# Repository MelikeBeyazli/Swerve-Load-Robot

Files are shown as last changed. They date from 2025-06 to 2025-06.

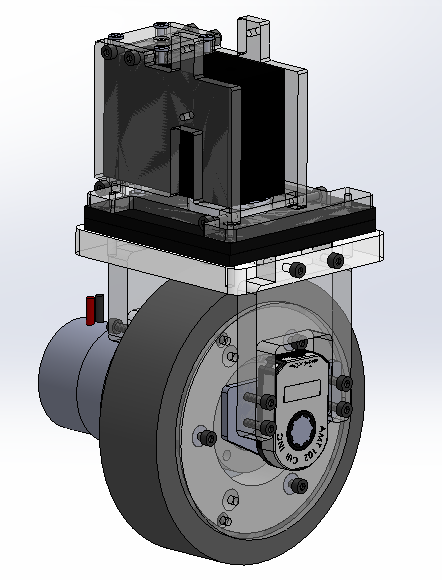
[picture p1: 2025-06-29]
Cad/2_Tekerler-Sümeyye/Yük Tekeri/swerve drive pic2.png

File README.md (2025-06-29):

# Swerve-Load-Robot — Tasarım & Mekanik Analiz Projesi  
*(Mekatronik Mühendisliği Tasarım Dersi, 2024 Bahar Dönemi)*

Bu depo; makaslı kaldırma mekanizması ve swerve‑drive tahrik sistemine sahip  
dört tekerlekli bir **yük robotunun** SolidWorks CAD dosyalarını ve ANSYS tabanlı  
mekanik analiz çıktılarının özetlerini içerir. Çalışma, 2024 ilkbaharında ders  
projesi olarak yürütülmüş ve aynı yıl bir ulusal sempozyum bildirisi ile hakemli  
dergi makalesi biçiminde yayınlanmıştır.

---

## 1 | Ekip ve Sorumluluklar

| Klasör | İçerik | Sorumlu Öğrenci |
|---|---|---|
| `cad/car_body/` | Beş karoser prototipi ve final gövde | **Melike Beyazlı** |
| `cad/chassis/`  | Sigma‑profil şasi tasarımları | **Görkem Burak Taşkın** |
| `cad/wheels/` | Yedi PU‑kaplı tahrik tekeri modeli | **Sümeyye Alp** |
| `cad/lift/` | Üç makaslı kaldırma tasarımı | **Zeynep Işık**, **Görkem B. Taşkın** |
| `cad/swerve-load-robot/` | Nihai bütünleşik montaj (.SLDASM) | Tüm ekip |
| `docs/` | • **Makale**: Mısır, O., Beyazlı, M., Alp, S., Taşkın, G. B., *vd.* (2024). *Design and Mechanical Analyses of Mobile Robot with Swerve Driving System*. **Türk Doğa ve Fen Dergisi, 13(4), 66‑84.** doi:10.46810/tdfd.1506516  <br>• **Bildiri**: Beyazlı, M., Alp, S., Taşkın, G. B., Işık, Z. (2024). *Dört Tekerlekli Yük Taşıma Özelliğine Sahip Otonom Mobil Robotun Geliştirilmesi.* UEBAS’24, 16‑17 Mart 2024.  |

---

## 2 | Çalışma Takvimi (2024)

| Ay | Önemli Adımlar |
|----|---|
| Şubat | Konsept belirleme; ilk karoser ve şasi çizimleri |
| Mart  | Teker prototipleri; IV. Ege Bilimsel Araştırmalar Sempozyumu bildirisi |
| Nisan | ANSYS Workbench kurulumu; malzeme kütüphanesi oluşturma |
| Mayıs | Karoser, şasi, teker ve kaldıraca ait ayrık FEA çalışmaları |
| Haziran | Nihai montaj **Swerve‑Load‑Robot** tamamlandı |
| Temmuz | Bandırma DergiPark makalesi tamaml anıp gönderildi |

---

## 3 | Klasör Yapısı

```
swerve-load-robot/
├── cad/
│   ├── car_body/            # Karoser taslakları
│   ├── chassis/             # Şasi modelleri
│   ├── wheels/              # Teker varyasyonları
│   ├── lift/                # Kaldırma mekanizmaları
│   └── swerve-load-robot/   # Nihai montaj (.SLDASM)
├── docs/
│   ├── Swerve...Robot_Tasarımı.docx
│   ├── Dört_Tekerlekli_Yük_Taşıma_Robot.pptx
│   └── Sunum_Özeti_Dört_Tekerlekli_Yük_Taşıma.docx
└── README.md
```

---

Bu özet, depodaki her bileşenin **kim** tarafından hazırlandığını ve **nerede**  
bulunduğunu netleştirir. Ayrıntılı CAD modelleri ve analiz raporları ilgili  
klasörlerde mevcuttur.

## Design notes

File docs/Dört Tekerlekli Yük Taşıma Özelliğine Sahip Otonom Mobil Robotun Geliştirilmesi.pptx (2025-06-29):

## Dört Tekerlekli Yük Taşıma Özelliğine Sahip Otonom Mobil Robotun Geliştirilmesİ

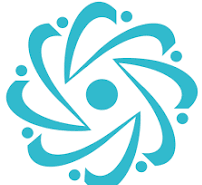
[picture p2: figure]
Bursa Teknik Üniversitesi | Bursa

Bursa Teknik Üniversitesi
Mekatronik Mühendisliği

Melike Beyazlı
Sümeyye Alp
Görkem Burak Taşkın
Zeynep Işık
Dr. Öğr. Üyesi Oğuz Mısır

## içindekiler

Endüstriyel Robotlara Giriş
Tasarlanan Aracın Görevleri
Elektronik ve Yazılım Tasarımı
Mekanik Tasarımı

## Endüstriyel Robotlara Giriş

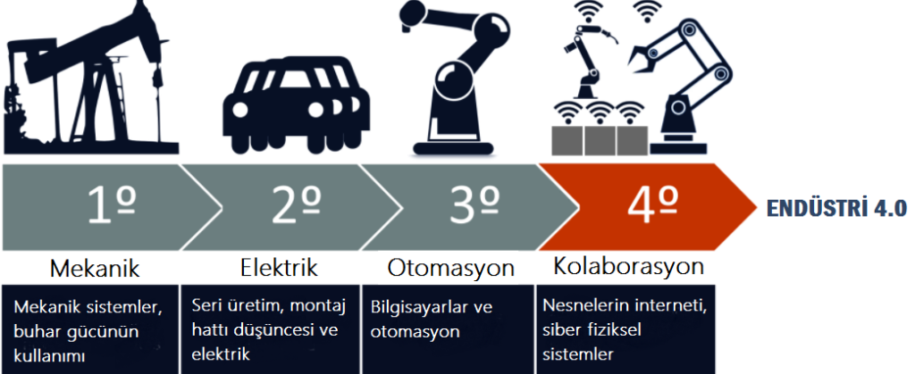
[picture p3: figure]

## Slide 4

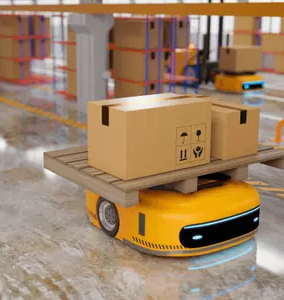
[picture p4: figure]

Endüstriyel kullanımda yaygın olarak kullanılan AGV'ler (Otonom Güdümlü Araçlar), otomatik olarak malzemeleri taşımak, yükleri yerinden almak ve belirlenmiş hedeflere teslim etmek için kullanılan otonom araçlardır. AGV'ler fabrikalarda, depolarda, lojistik merkezlerinde ve benzeri endüstriyel tesislerde yaygın olarak kullanılır.

## Tasarlanan Aracın Görevleri

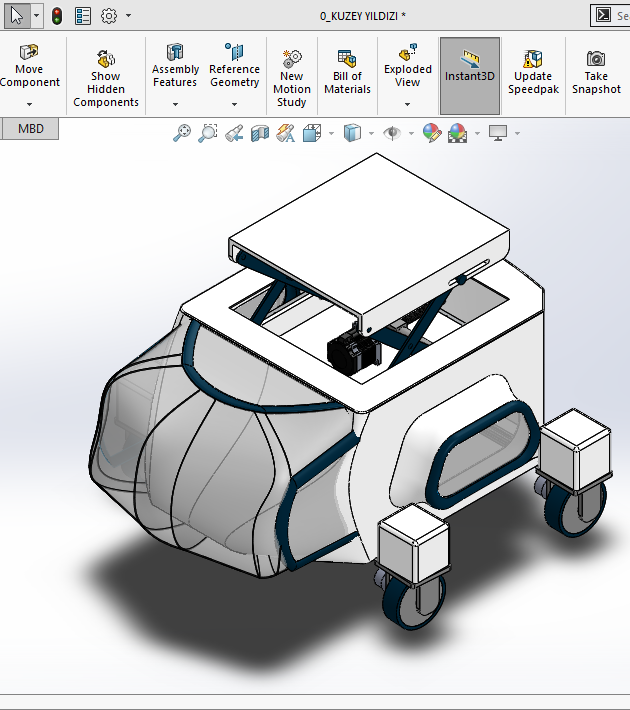
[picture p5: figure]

- Haritalandırma,
- Yol takibi,
- Engelden kaçınma,
- Yük alma bırakma,
- Fazla yük tespiti.

## Elektronik ve Yazılım Tasarımı

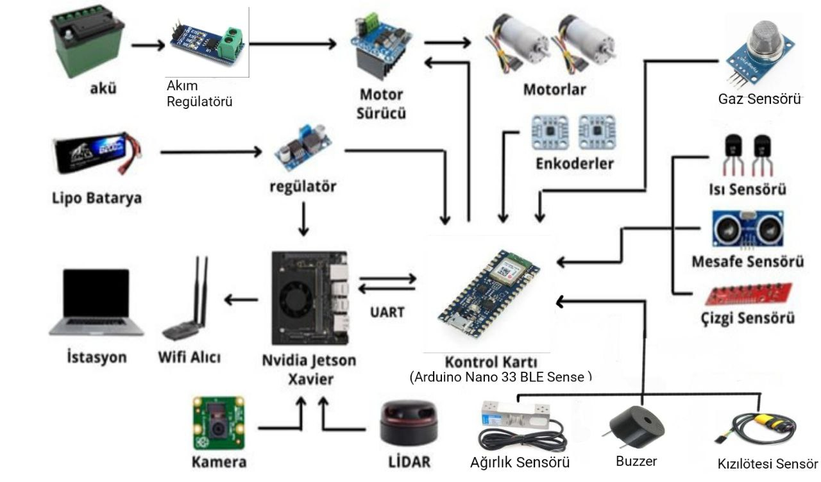
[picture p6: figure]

## Mekanik Tasarım

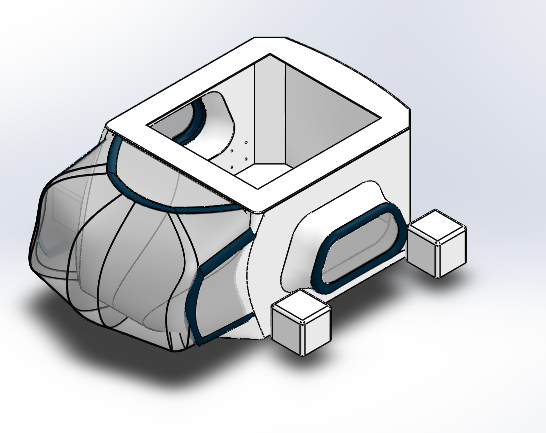
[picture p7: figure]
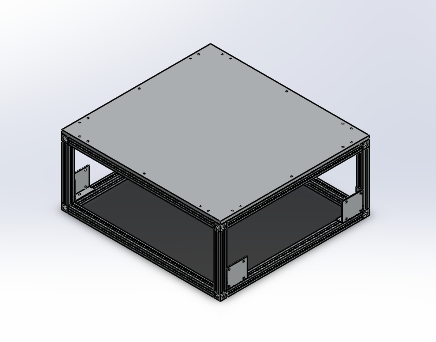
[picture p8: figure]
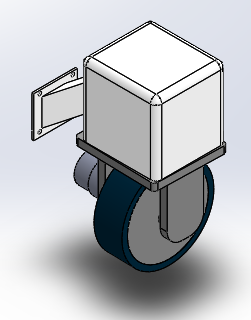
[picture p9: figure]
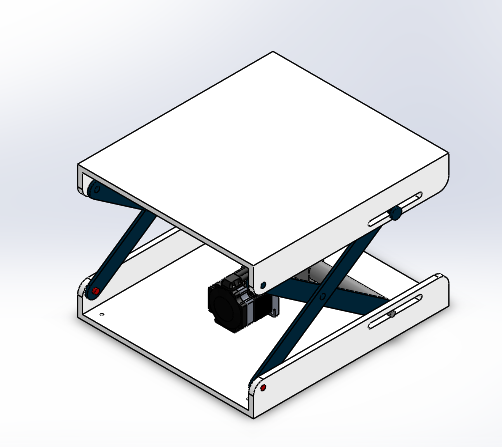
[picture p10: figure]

## KaROSer

Karbon Fiber malzeme
Yükseklik = 355 mm
Genişlik = 670 mm
Uzunluk = 885 mm

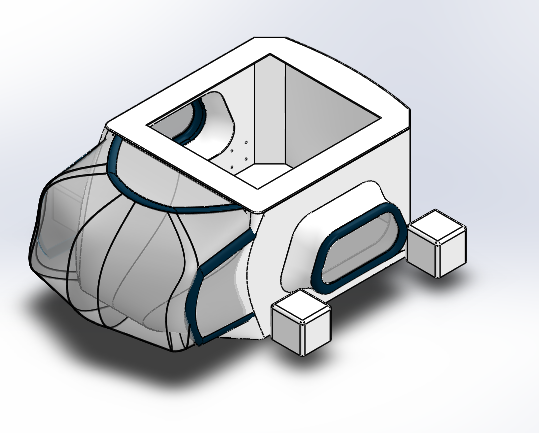
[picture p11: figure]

## Şasi Tasarımı

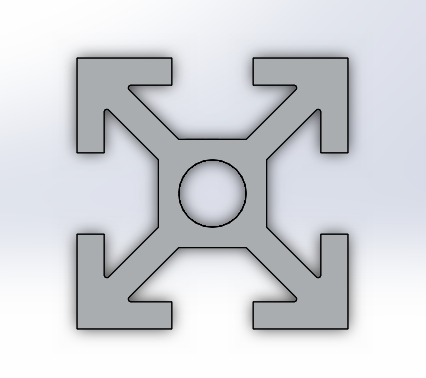
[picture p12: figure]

- Teknik Bilgiler

- Minimum Yük Kaldırma = 150 Kg
- Uzunluk = 460 mm
- Genişlik=500 mm
- Yükseklik=228 mm

- Sigma Profil

- 20x20 Alüminyum Sigma Profil:
- Hafiflik
- Yüksek Dayanıklılık
- Esneklik
- Kolay işlenebilirlik

## Kaldıraç Tasarımı

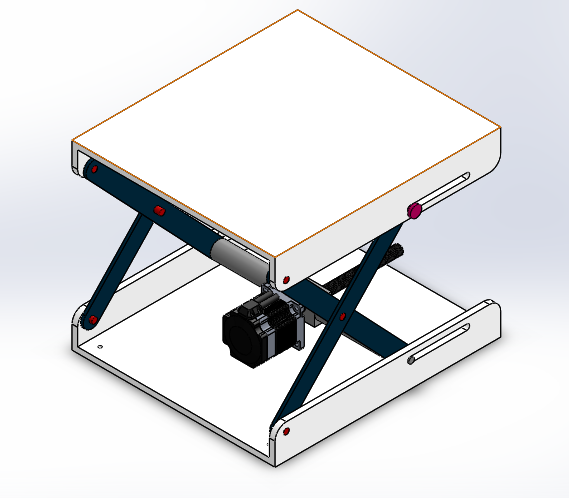
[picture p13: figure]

- Yüksek yük taşıma kapasitesi,
- İyi stabilite ,
- Kompakt tasarım,
- Esneklik,
- Dayanıklılık,
- Kullanım alanları genişliği.

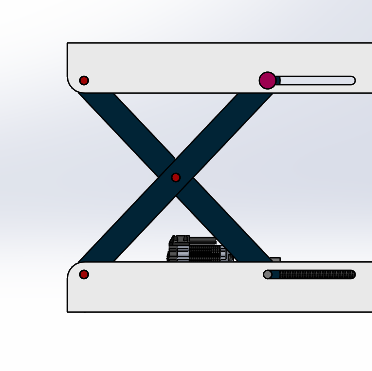
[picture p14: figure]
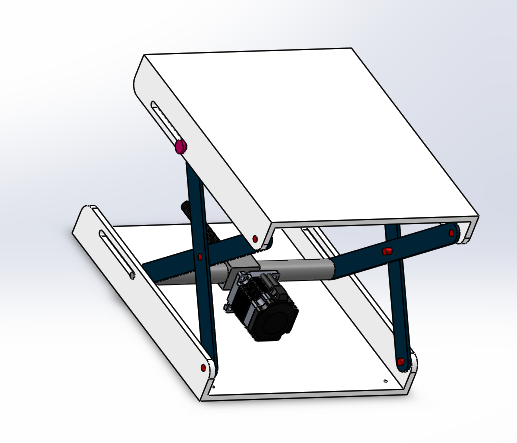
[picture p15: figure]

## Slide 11

- Makas

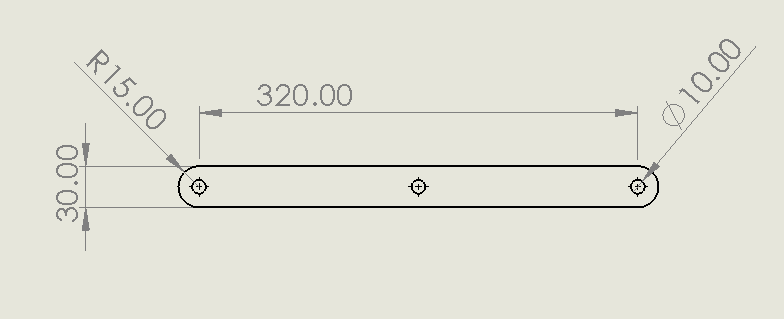
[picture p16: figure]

Çeliğin Özellikleri:
- Yoğunluk ρ = 7.7 ÷ 8.1 [kg/dm3]
- Elastiklik modülü E=190÷210 [GPa]
- Poison oranı ν = 0.27 ÷ 0.30
- Termal iletkenliği κ = 11.2 ÷ 48.3 [W/mK]
- Termal genleşme α = 9 ÷27 [10-6 / K]

- Platform

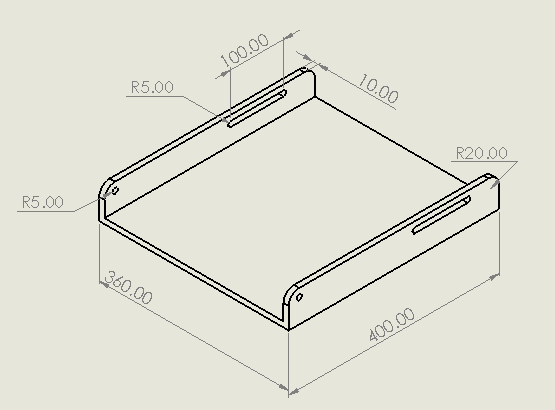
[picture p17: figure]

Alüminyumun Özellikleri:
- Akma Dayanımı = 140 Mpa
- Çekme Dayanımı = 180 Mpa
- Uzama = % 10
- Elastisite= 69 GPa

## Kaldıraç Matematiği

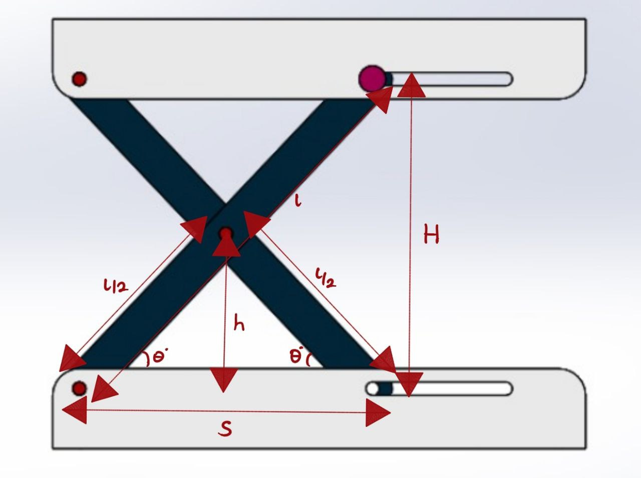
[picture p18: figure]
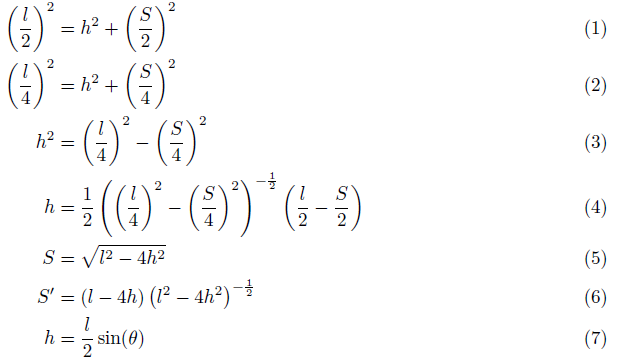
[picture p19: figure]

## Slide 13

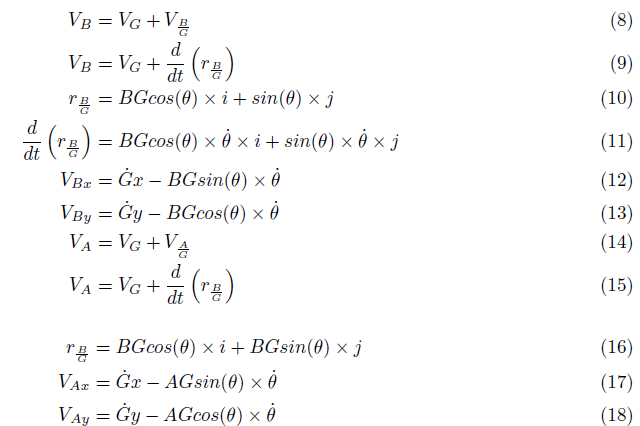
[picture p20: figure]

## Teker Tasarımı

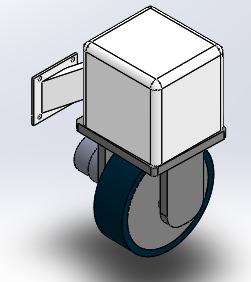
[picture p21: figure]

- Alüminyum Üzeri Poliüretan Tahrik Tekerleği
- Tekerleğin çapı 125mm,
- Genişliği 40mm,
- Yüksek ağırlıklara dayanaklılık,
- Anti-patinaj .

## Dinlediğiniz için Teşekkür Ederiz

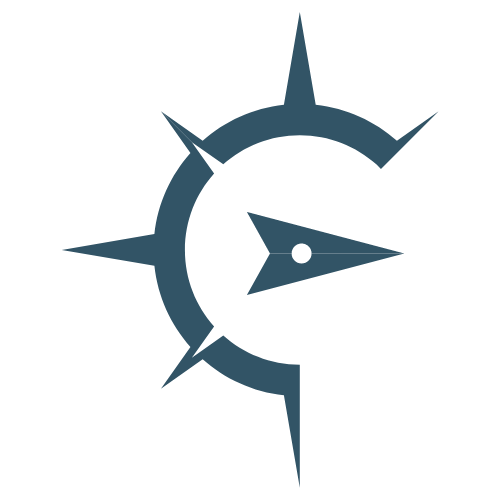
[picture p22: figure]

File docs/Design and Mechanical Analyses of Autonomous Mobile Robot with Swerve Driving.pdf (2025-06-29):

66

Volume 13, Issue 4, Page 66-84, 2024 | https://doi.org/10.46810/tdfd.1506516 | Research Article

Design and Mechanical Analyses of Autonomous Mobile Robot with Swerve Driving System

Oğuz MISIR¹*
, Melike BEYAZLI ¹

, Sümeyye ALP 1
,

Görkem Burak TAŞKIN ¹

, Zeynep IŞIK¹

1Bursa Teknik Üniversitesi, Mühendislik ve Doğa Bilimleri Fakültesi, Mekatronik Mühendisliği, Bursa, Türkiye Oğuz MISIR ORCID No: 0000-0002-3785-1795 Melike BEYAZLI ORCID No: 0009-0005-6315-794X Sümeyye ALP ORCID No: 0009-0006-5922-8706 Görkem Burak TAŞKIN ORCID No: 0009-0004-0483-0404 Zeynep IŞIK ORCID No: 0009-0005-1388-7194

*Corresponding author: oguz.misir@btu.edu.tr

(Received: 28.06.2024, Accepted: 06.11.2024, Online Publication: 30.12.2024)

Keywords
Finite element
analysis,
Mobile robot,
Autonomous

Abstract: The use of mobile robots has become increasingly prevalent in various sectors, including industry, healthcare, logistics, and services. One of the most crucial attributes of these robots for their intended applications is their capacity to transport payloads. Autonomous mobile vehicles capable of carrying payloads are robots that process data received from their environment through electronic components. They contain and deliver the load to the target location in accordance with the data. This study presents the design of a mobile robot with scissor lift and swerve driving systems. Finite element analysis was employed to investigate the stress and deformation behavior of the designed vehicle under a load. The suitability of the materials used for the design was verified as a result of the analyses. Subsequently, the ability of the real-time driving algorithms to act in possible scenarios is tested in a simulation environment.

Swerve Sürüş Sistemine Sahip Otonom Mobil Robotun Tasarımı ve Mekanik Analizleri

Anahtar
Kelimeler:
Sonlu
elemanlar
analizi,
Mobil robot,
Otonom

Öz: Mobil robotlar, endüstride, sağlık sektöründe, lojistik sektöründe ve servis hizmetlerinde kullanımıyla giderek artan popülerlik kazanmıştır. Bu robotların kullanım amaçları arasındaki en önemli özellikleri arasında faydalı yük taşıyabilme kabiliyetleridir. Bu maksatla mobil robotun yük taşıma kabiliyetinin kazandırılmasında tasarım ve donanım önem kazanmaktadır. Bu çalışmada, makaslı kaldıraç sistemine sahip olan ve “swerve” sürüş sistemiyle hareket eden mobil robotun tasarımı sunulmaktadır. Tasarlanan aracın yük altındaki gerilim ve deformasyon değişimlerini incelemek için sonlu elemanlar kullanılmıştır. Analizler sonucunda kullanılan malzemelerin tasarıma uygunluğu kontrol edilmiştir. Yapısal analizi tamamlanan aracın gerçek zamanlı sürüş algoritmalarının olası senaryolar karşısındaki hareket kabiliyeti simülasyon ortamında test edilmiştir.

### 1. INTRODUCTION

In a world characterized by constant change, the capacity to adapt to novel situations and acquire new skills and abilities is essential. Within this context, robots capable of multidirectional movement in time and space are utilized [1]. Robots are technological systems that perceive their environment for specific purposes and generate motion plans by evaluating the information they obtain [2]. They have a wide range of applications, including industrial

Tr. J. Nature Sci. Volume 13, Issue 4, Page 66-84, 2024

67

manufacturing, healthcare, space exploration, and domestic use [3]. Consequently, robotics has become a pervasive feature of the contemporary world, including roles directly oriented towards humans, and is employed in numerous contexts. The human need for technological solutions, which has consistently influenced the evolution of technology, has led to the development of mobile robots, as stationary robots are no longer sufficient.

Autonomous robotic systems are increasingly being employed to develop innovative tools to enhance work efficiency and perform multiple operations in diverse environments, as well as a potential countermeasure to the impending issue of labor shortages [4]. Autonomous mobile robots (AMR) are defined as robots that operate in accordance with environmental information obtained by sensors, cameras, artificial intelligence applications, and other means. They autonomously perform assigned tasks [5]. In contrast to many industrial robots, mobile robots are capable of navigating to their task locations without human intervention, possess expansive movement areas, and complete their tasks by reaching the desired location while avoiding obstacles under varying conditions [6]. Mobile robots are increasingly utilized in numerous industrial and specialized applications. They can be designed according to the specific requirements of their intended use. Mobile robots, which are equipped with various components for different purposes and controlled by diverse software algorithms, are capable of detecting environmental data such as lines, light, and sound autonomously and moving automatically. Alternatively, they can be controlled manually with the assistance of a user interface. The motion mechanisms of mobile robots represent a crucial aspect. Although the motion mechanisms in the vehicle affect numerous parameters, the selection of an appropriate wheel for the vehicle and the creation of wheel configurations on the chassis result in the vehicle being used with high efficiency [7]. Mobile robots are categorized into three types according to their motion mechanism: wheeled, tracked, and legged systems.

The wheel is the most commonly used motion mechanism in mobile robots. Wheeled robots have been the most prevalent locomotion mechanism due to their simple structure, high acceleration, and ease of control. One of the most widely used wheeled mobile robots in industry is the autonomous mobile robot for load handling [8].

The designs of robots used for load-carrying vary according to the manner in which they lift and carry the load. In this context, the weight and dimensions of the load to be transported are the most critical parameters in the system design. Mechanical tests of prototypes made in this field provide great convenience for the design process, cost, and optimization through simulation programs. Consequently, software programs are capable of conducting analyses of interdisciplinary studies, such as mechanics, structural analysis, computational fluid dynamics, and heat transfer, employing the finite element method [5].

The Finite Element Method (FEM) is a numerical analysis technique used to solve complex engineering problems and predict the behavior of a structure or system when subjected to physical effects. This method is based on the principle of dividing the design into small finite elements and analytically examining each element [9]. FEM allows for the identification of potential weak points in the design, optimization of material usage, and verification of safety factors. Additionally, it simulates the system's stress, deformation, and other mechanical properties before producing physical prototypes, thereby helping to reduce costs and accelerate the design process. Consequently, it ensures that the design can operate reliably even under the most challenging conditions, thus preventing potential design errors.

This paper presents the design of an autonomous mobile robot with load-carrying capability developed in a Computer-Aided Design (CAD) environment. The mechanical system of the designed mobile robot was analyzed using the Finite Element Analysis (FEA) method to assess total deformation and stress. Furthermore, the wheel driving capability of the vehicle and mechanism of the scissor system were tested in a simulation environment. In the rest of the paper, Section 2 describes the system, programs used, general control mechanism, structural characteristics of the designed vehicle, and types of mechanical analysis used. Section 3 presents the analysis set-up and test results. Section 4 discusses the overall conclusion of the paper.

### 1.1 Related Works

In this section, within the scope of our study on AMRs, we review the literature on the utilization of AMRs in the industrial and social domains, mechanical analysis, and simulations of driving systems. The keywords “AMR,” “ANSYS,” “Driving Systems,” and “Simulation” were employed in the literature search. A summary of the pertinent studies identified using these keywords is presented in Table 1. AMRs utilized for material handling and storage in the industry can be readily integrated with various mapping techniques, providing a significant advantage for transportation operations.

AMRs are employed not only in industrial logistics but also in numerous areas for societal benefits. AMRs have recently become prevalent, particularly in the healthcare sector, where they have been effectively utilized for the transportation of medicines and food within hospitals. Baskoro et al. [10], in their study titled “An Autonomous Mobile Robot Platform for Medical Purpose”, asserted that the highly maneuverable AMR named ROM20 can be utilized in various applications such as disinfectant mist spraying and food distribution heating in a hospital environment. This study demonstrates the functionality of AMRs in the healthcare field. In another study by Yan et al. [11] posited that AMRs provide significant advantages in material-handling operations in industrial applications. They also noted that AMRs face flexibility challenges in path alterations but overcome this issue by employing Simultaneous Localization and Mapping (SLAM) techniques.

68

Recent | advancements | in | drive | mechanisms | for
autonomous robots with high maneuverability have led to substantial progress. The work of Dhelika et al. [12] serves as an exemplar, wherein a motorized hospital bed utilizing a swerve drive mechanism was developed to provide holonomic mobility in healthcare environments. The simplicity and cost-effectiveness of the swerve drive system facilitate its integration into existing systems with minimal modifications. Additionally, the work by Ziqi et al. [13] presents significant research on drive mechanisms and mobility systems for autonomous mobile robots. This study thoroughly examines the advantages and challenges of swerve drive systems, proposing novel methods for enhancing maneuverability and mechanical durability. The research strengthens the scientific foundation of the swerve drive system utilized in our vehicle and directly relates to previous studies on drive mechanisms.

The mechanical design and analysis of autonomous mobile robots have been extensively studied using simulation tools such as Ansys, which provides robust capabilities for structural and dynamic evaluations. Demir et al. [14] conducted static and dynamic analyses of a mobile transportation robot with mecanum wheels, utilizing Ansys Workbench to assess the robot's structural integrity under a maximum load of 300 N. The study calculated critical parameters such as maximum stress and deformation to validate the design under extreme operating conditions. In another study, Prabhakaran et al.

[15] focused on a mobile robot designed for material handling, analyzing the structural behavior of the robot's chassis under a 300 N payload. The researchers utilized Ansys to simulate and validate the mechanical integrity of the chassis, ensuring the design could withstand the operational stresses, with maximum stress values of 35.99 MPa and deformation calculated at 0.000248 m.

Simulations of autonomous mobile robots and robotic systems are extensively employed to enhance the accuracy and efficiency of real-time applications. Koca et al. [16] simulated a mobile tank-driving robot in ROS and Gazebo environment. In this study, the physical and inertial properties of the robot were defined, and the motion and control of the robot were simulated. The simulations have made significant contributions in terms of identifying the challenges that mobile robots may encounter in real environments. Specifically, modeling and simulation of tank driving systems increase the reliability of real-time applications and facilitate the development of these systems. Ağralı et al. [17] simulated robot arms with the V-REP (CoppeliaSim) simulator. In the study, MATLAB and V-REP were synchronized to control the robot arm with a PID controller, and trajectory tracking and torque control were simulated with forward and inverse kinematic methods. This approach has been employed to ensure the accurate operation of robot arms, and such simulations are considered an important step towards more precise control of robotic systems.

Table 1. Summary of key studies on AMRs
Study | Focus Area | Techniques Used | Key Findings
Baskoro et al. (2020) [10] | Use of AMRs in healthcare | ROM20 AMR in hospital environments | The developed ROM20 AMR was used in various hospital applications such as disinfectant spray and food distribution, demonstrating the functionality of AMRs in healthcare.
Yan et al. (2023) [11] | Material handling in industrial environment | SLAM (Simultaneous Localization and Mapping) | AMRs provide significant advantages in material handling, overcoming flexibility issues in path changes through SLAM techniques.
Dhelika et al. (2021) [12] | Holonomic mobility and drive mechanism | Swerve drive mechanism | The swerve drive mechanism-equipped motorized hospital bed offers simplicity and cost-effectiveness, enabling easy integration into existing systems.
Zhao et al. (2023) [13] | Drive mechanisms and mobility systems in AMRs | Swerve drive system | The study presents new approaches to enhance the maneuverability and mechanical durability of swerve drive systems in AMRs.
Demir et al. (2021) [14] | Mechanical analysis | Static and dynamic analysis with Ansys Workbench | The Mecanum wheeled mobile robot's ability to safely operate under a load of 300 N was analyzed.
Prabhakaran et al. (2021) [15] | Structural durability analysis | SolidWorks and Ansys | The structural design of a mobile robot capable of carrying 30 kg was analyzed to determine maximum stress and deformation values.
Koca et al. (2020) [16] | AMR simulation | Simulation in ROS and Gazebo | A tank-steer mobile robot's physical and control features were successfully simulated for real-time applications.
Ağralı et al.(2020) [17] Robot arm simulation | | MATLAB and V-REP synchronization, PID controller | The robot arm’s torque and trajectory control were successfully simulated using inverse and forward kinematic methods.

### 2. MATERIAL AND METHOD

The AMR development phase is divided into design, mechanical analysis, hardware, software, and simulations. In this study, the CAD program SolidWorks was used for vehicle design. SolidWorks was chosen because of its user-friendly interface, comprehensive range of tools, and robust simulation capabilities. Among CAD programs, SolidWorks facilitates the modeling of complex geometries and rapid visualization of designs. It is also compatible with analytical methods such as the FEM and simulations that incorporate strength analysis [18]. The Ansys software utilized in these simulations directly supports SolidWorks file formats, such as. stl, .sldasm, and parasolid, enabling the seamless transfer of designs to the analysis environment. This approach mitigates the potential issues that may arise during file transfer. Driving
simulations | were | conducted | in | a | CoppeliaSim
environment to perform the necessary tests, and the AMR behavior in various scenarios was investigated. Figure 1 shows the design stages of the mobile robot with payload-carrying capability.

69

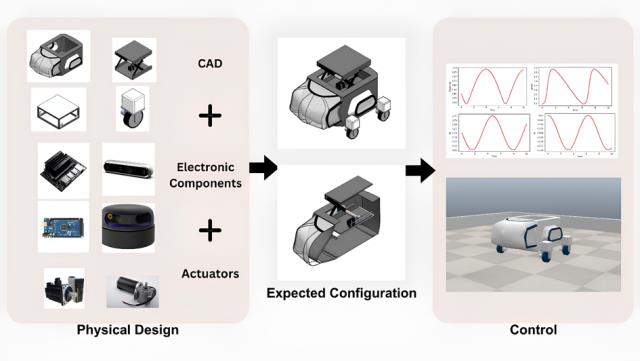
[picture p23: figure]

Figure 1. Design stages of a mobile robot with payload-carrying capability

Mechanical analysis is an essential stage in which a model designed with SolidWorks and prepared for analysis must be performed prior to production, particularly when its primary function is load-bearing. Ansys, which is utilized for the mechanical analysis of the vehicle, conducts the analysis using the FEM.

FEM is the process of transforming a finite function into a vector space using numerical methods in the domain of infinite function. [19]. The structure under analysis is divided into a specific number of small parts, termed finite elements, with the objective of mathematically examining the 'behavior' of each part using formulas derived from partial differential equations. The process from a model's real-world state to its discretized state is shown in Figure 2.

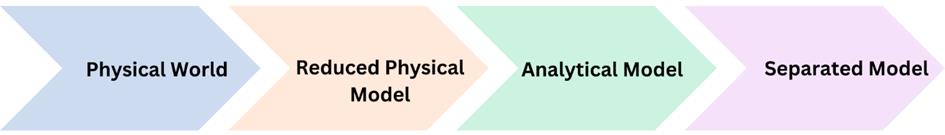
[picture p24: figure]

Figure 2. The process from a model's real-world state to its discretized state

FEA encompasses specific components such as thermal,
electromagnetic, | fluid, | and | structural | operating
environments. This analytical method provides a detailed visualization of structural deformation and torsion, while simultaneously illustrating the distribution of stresses and displacements. In structural simulations, FEA facilitates the production of stiffness and strength visualizations and contributes to the optimization of weight, materials, and costs. Furthermore, it offers a diverse range of simulation options to regulate the complexity between the modeling and analysis of a system.

In FEA, objects with complex geometries, which are challenging to analyze as a single unit, are subdivided into numerous smaller parts and analyzed separately. These subdivisions are referred to as “mesh”. The mesh constitutes an integral component of the model and requires careful control to obtain the optimal results. Elements comprising small shapes are interconnected by points (nodes) that form the geometry of the model. Figure 3 illustrates the node structure that connects the elements [20].

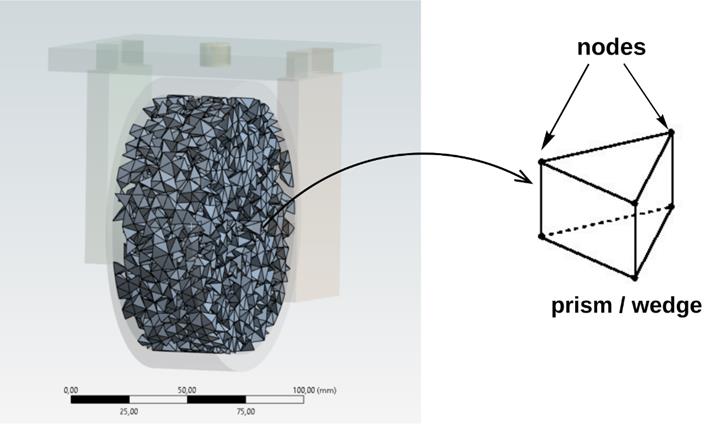
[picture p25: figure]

Figure 3. Illustrates the node structure that connects the elements

Mesh quality, element size, and element type are the most critical factors to consider when conducting a mesh analysis. The element size can be reduced in specific regions of the model, which is particularly crucial in critical areas where a high stress or deformation is anticipated. The mesh quality is ensured by through the uniformity of the element shape and optimized size distribution. Optimizing the mesh structure enhances accuracy while maintaining a reasonable solution time. To improve the mesh quality, adjustments are made based on the type and quantity of the elements utilized. Different element types and sizes influence the analysis results [21].

Mesh types are generally categorized as two-dimensional and three-dimensional. Two-dimensional structures are classified as triangular, and quadrilateral meshes. Triangular mesh comprises three-sided elements, and is generally preferred for surface modeling, and is utilized for modeling complex surfaces owing to its flexible structure. A quadrilateral mesh consists of four-sided elements and is often favored to provide more stable results in smooth geometries. Examples of three-
dimensional | mesh | structures | include | tetrahedral,
hexahedral, and wedge meshes. Tetrahedral mesh consists of tetrahedron elements and enables the modeling of complex geometries with high accuracy. Hexahedral mesh comprises hexahedron elements and is suitable for planar structures or regular geometries. Wedge mesh contains prism/wedge elements and is employed in transition zones, complex structures, or when detailed modeling of specific parts is required, which is particularly advantageous in areas that require precise examination.

Selecting appropriate mesh element types for the part reduces the number of elements, thereby decreasing the analysis time and post-analysis processing time. Furthermore, for nonlinear systems and instances in which the arrangement of elements is physically significant, the utilization of hexahedral and quadrilateral

70

shaped elements is more suitable. Consequently, hex20, tet10, and wed15 were predominantly used in the analysis. The mesh types are also formulated according to the combination of the element types. The mesh types vary based on the arrangement and structure of the elements. Each mesh type presents distinct advantages and disadvantages; therefore, a type that aligns with the requirements of the application should be selected. A structured mesh is preferable for simpler geometries and when expeditious solutions are required, whereas a nonstructured mesh offers a more flexible solution for complex geometries. Hybrid mesh is frequently utilized to balance both accuracy and solution efficiency in complex models. An adaptive mesh is an appropriate method to achieve precise results; however, the processing time and computational cost are higher [21].

The appropriate selection of the mesh structure and type is a critical factor that directly influences the accuracy of the simulation results and the efficiency of the computational process. The determination of which mesh type to employ should be based on consideration of the model geometry and the parameters to be analyzed. Figure 4 shows the Ansys interface of the mesh analyzed part.


Figure 4. Ansys interface of the mesh analyzed part

Ansys is comprised of various programs for conducting different analyses. In this study, Workbench and Mechanical from the Ansys suite were utilized. Ansys Mechanical, which performs static and dynamic analyses of parts and assemblies in complex structures as well as torsion, stress, vibration, and heat transfer analyses, simulates this work and enables the observation of their behavior in real-world conditions [22]. The steps of the FEM in Ansys are schematized in flowchart form in Figure 5.

71


Figure 5. The steps of the FEM in Ansys

In the subsequent phase, simulations are utilized to examine real-time robot system design, modeling, and
production, | encompassing | computer, | electronics,
mechanics, | and | control | systems, | among | other
interdisciplinary aspects. This process evaluates the performance of the model in the design verification stage prior to initiating production under the specified environmental conditions. Given that simulators are appropriate for conducting necessary tests of a theoretically designed robot or robotic system in a virtual environment, numerous robot simulators such as Gazebo, Webots, and CoppeliaSim have been developed [17]. Among these platforms, CoppeliaSim, which was employed in this study, facilitates the simulation of complex robotic scenarios by creating and manipulating 3D models of robots, sensors, and environments [23]. In the CoppeliaSim environment, the system requires control through code blocks to enable the movement and processing of data received from sensors of the mobile robot. Within the CoppeliaSim simulation environment, Lua Script can be utilized to control the mobile robot's movement via code blocks; alternatively, programming languages such as MATLAB, C/C++, or Python can be employed. Python, a high-level programming language known for its versatility and extensive library support, was selected for the implementation of the motion and deep learning algorithms of the mobile robot [17].
The Spyder integrated development environment (IDE) was employed to develop and manage Python code in conjunction with CoppeliaSim. Spyder provides support for developers and contributes to more effective simulation execution [24].

### 2.1. Robot Kinematics

Robot kinematics is employed to investigate the motion of robots within a given workspace. By leveraging robot kinematics, the position and orientation of the end effector and the corresponding joint variables can be determined within the robot's operational environment. Robot kinematics is divided into two distinct categories: forward kinematics and inverse kinematics. The forward kinematics of the robot is employed to determine the position of the end effector corresponding to the value of
each joint | variable, | while | each joint | variable
corresponding to the position of the end effector is calculated by inverse kinematics [25].

### 2.1.1. Wheel kinematics

As the wheel system of the vehicle, as shown in Figure 6, a DC motor was used to rotate the wheel, and a servo motor was used to direct the wheel at certain angles to increase the movement capacity. A total of 8 motors were used in each wheel, one DC motor and one servo motor.


Figure 6. Single wheel structure of the designed vehicle

72

Vehicle structures with an independent translation and steering module on each wheel are called Wheel Independent Steering or Swerve Drive. Such drive systems are used in weight transportation, agricultural machinery or the Mars Rover. Advantages of the swerve drive system:

- The system provides a high level of mobility. In swerve driving, the direction of movement and orientation are independent, allowing the robot to face forward while moving sideways. Furthermore, the Instantaneous Center of Rotation (ICR) is not fixed in swerve driving, as in ackermann and differential driving. This flexibility allows it to combine linear and rotational movements, which other driving systems cannot do.
- They have wheel structures suitable for payload carrying. Although the degree of freedom is the same as for swerve driving, omni wheels cannot carry the same load due to the lower carrying capacity of the rollers that allow them to move sideways.
- It does not depend on wheel deflections as a multi-wheel differential drive does. This allows the robot to use more motor torque to move forward, consuming less power. While omni and mecanum wheels have movement limitations due to wheel clogging in dust and dirty environments, swerve drive wheels do not have such problems [26]. Figure 7 shows the wheel configurations.


Figure 7. Wheel configurations

In short, in the designed autonomous mobile vehicle, the wheels are controlled independently at different angular speeds. If we consider the single-wheel system, the DC motor performs a rotational motion in the y-axis, which allows the wheel to perform a translational motion in the x-axis. The servomotor adjusts the wheel orientation by rotating in the z-axis. Figure 8 shows the vehicle-wheel axis sets.


Figure 8. Vehicle-wheel axis sets

The vector sum of the wheel speeds is shown in Equation
1. If the position of the vehicle relative to a fixed set of axes x and y, the direction of our position axis remains constant as the vehicle moves. The position of the single wheel structure relative to the axis of rotation is
r⃗ = (rx, ry, 0) . When the robot moves with a linear
velocity | v⃗ = (vx, vy, 0) and | an | angular | ω⃗⃗ =
(0, 0, wx

) the linear velocity of the wheel is calculated as in Equation 2 [27].

v1

⃗ ⃗ +v2

⃗ ⃗ +v3

⃗ ⃗ +v4

⃗⃗ = V⃗⃗ | (1)

Vm

⃗⃗⃗⃗ = V⃗⃗ + ω⃗⃗ × r⃗
(2)

The matrix form of the linear velocity of the wheel is presented in Equation 3. If we assume that the angular velocity of the vehicle is zero, the displacement matrix is as shown in Equation 4. Substituting this equation into Equation 3, Equations 5 and 6 are obtained.

73

[

Vmx
Vmy] = [

1 0 −ry
0 1 rx

] [

Vx
Vy
ω

]
(3)

(r0x, r0y) : The initial position of the wheel in relation to the center of the robot
θ(t) : Heading over time
t : Duration
[

rx
ry
] = | [
cos(ωt) | −sin(ωt)
sin(ωt) | cos(ωt)

] [

r0x
r0y

]

(4)

Vmx(t) = vx − ω × (r0x × sin(ωt) + r0y × cos(ωt))

(5)

Vmy(t) = vy + ω × (r0x × cos(ωt) − r0y sin(ωt))

(6)

Vmx(t) = vx − ω x√(r0x
2 + r0y
2) x cos(ωt −
tan⁻¹
(r0x, r0y))

(7)

Vmy(t) = vy + ω × √(r0x
2 + r0y

2)

× cos(ωt −arctan (
− r0y, r0x)

(8)

By applying Equations 7 and 8, the vehicle velocity is calculated sinusoidally according to the origin. The velocity of the wheel:

θ(t) = arctan (vmy(t), vmx(t)) −

ωt , mod 2π

(10)

### 2.1.2. Lift system kinematics

Autonomous mobile robots with payload carrying capability require special payload lifting mechanisms to move payloads from one location to another. These
mechanisms | can | operate | both | manually | and
automatically. In general, scissor platforms are the preferred option, as they minimize the footprint of the payload lifting mechanism within the mobile robot and avoid the restriction of its mobility. These platforms are composed of scissors fixed to each other by bearings at the joints, and they offer a high payload capacity and durability.

For the movement of the scissors, the shaft of a servo motor is connected to the cylinder between two opposite scissors. With the rotation of this shaft connected to the servo motor, the scissor bases are shifted back and forth. So the upper platform to which the scissors are connected moves simultaneously on the vertical axis. In line with this movement, the height of the platform is adjusted and the load handling operation takes places. Figure 9 shows mechanism of lift system.


Figure 9. Lift system

W ∶ Distributed load
dAC : Length of AC
L ∶ Length of the scissors
ℎ ∶ Platform height
FBY and FDY ∶ Forces applied by the scissors to the platform Lw : Distance of the distributed load to the moment point

The vertical height of the scissors system to which the upper platform is connected is h, the angle of the scissors with the horizontal is θ and the connections between h and θ are shown in Equation (11-17).

L

2 = (

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
(11)

(

ℎ
2

)

2
= L

2 − (

dAC
2

)

2
(12)

dAC
2

= cos θ × L

(13)

(

ℎ
2

)

2
= L

2 − (cosθ × L )

2

(14)

(

ℎ
2

)

2
= L

2
(1 −cosθ

2
) = L

2 × sinθ

2

(15)

sin θ =

ℎ
2
L

, ℎ = 2 × L × sin θ

(16)

dAC
2

= L × cos θ

(17)

Instead of point forces, a distributed load is applied to the scissors system. The applied distributed load must be converted into a single singular force in order to substitute it in the moment and force equations. k represents the area of the upper platform where the distributed load is applied, m represents the total mass of the platform and the distributed load. W represents the total force exerted by the upper platform and the distributed load reduced to a singular force. This transformation is shown in Equation 18.

|⃗vm⃗ (t)| = √vmx
2 (t) + vmy

2 (t)

(9)

74

W = w × L | (18)

During the movement of the scissor system, points A and B remain stationary while points C and D move. Due to this motion, the velocity equations of points C and D are expressed in Equation (19-29) [19].
Velocity equations for point C:
VC = VG + VC G | (19)

VC = VG +

d
dt (rC

G

)

| (20)

rC

G

= |CG| × cosθ × i + sinθ × j | (21)

d
dt (rC

G

) = |CG| × cosθ ×

dθ dt × i × sinθ × dθ dt × j | (22)

VCx =

dG
dt − |CG| × sin θ ×

dθ
dt

(23)

VCy =

dG
dt −|CG| × cos θ ×

dθ
dt

(24)

Velocity equations for point D:

VD = VG + VD

G

| (25)

VD = VG +

d
dt (rD

G

)

| (26)

rD

G

= |DG| × cos θ × i + |DG| × sin θ × j (27)

VDx =

dG
dt − |DG| × sin θ ×

dθ
dt

(28)

VDy =

dG
dt − |DG| × cos θ ×

dθ
dt

(29)

The free body diagram of the scissors used in the lifting system is shown in Figure 10. In this diagram, the connection point of the scissors is called G and the connection points between the scissors and the platform are called A, B, C, D.


Figure 10. Free body diagram of scissors

The clockwise direction was determined as the direction of rotation of the moment and considered as the positive direction for the whole equation. Then, the total moment and the total force in the x and y axis were calculated for the whole system. These calculations are expressed in Equation below [19].

∑ MD = 0;−W × |Lw| +2 × FBy × |DP| = 0 | (30)
∑Fy = 0 ; 2FDy − W + 2FBy = 0 | (31)

∑Fx = 0; FGx − FAx = 0

(32)

∑Fy = 0; −FDy + FGy + FAy = 0

(33)

∑ Md = 0; −FBy × 2 × cos θ − FGy × L × sin(90 − θ) +FGx × L × sin θ

(34)

∑Fx = 0; FCx − FGx = 0

(35)

∑Fy = 0; − FBy − FGy + FCy = 0

(36)

### 2.2. Robot Controller

Sensors and simulation environments are often used in robots to obtain the information required for joint handling, such as robot positions, velocities and interaction forces between the load and mobile robots [28]. In order to analyze the motion of the mobile robot in real environment, the URDF file of the vehicle designed in Solidworks is exported to the CoppeliaSim environment. Figure 11 shows the vehicle exported to the CoppeliaSim environment. URDF (United Robotics Description Format) file is a language format written in

75

accordance with XML (Extensible Markup Language) language structure to describe robots. In this file, “continuous” is used for continuous rotation and “revolute” is used for rotation within a certain angle range.


Figure 11. The vehicle exported to CoppeliaSim environment

Python was used to control the parameters of the vehicle exported to the CoppeliaSim environment. To establish a connection between CoppeliaSim and Python language, Spyder IDE, which has an easy and understandable interface and can be easily integrated with CoppeliaSim, was used. In this way, the program is made ready to control the parameters such as velocity, direction and angle of the joint that give the mobile robot the ability to move.

### 2.3. System design

One of the challenges faced by mobile robots is the problem of localization in an indoor environment. Inaccurate localization can lead to inefficient path planning and inaccurate detection of obstacle locations. Therefore, it is possible to improve the indoor localization of mobile robots by using different sensors. Sensors integrated into the robot include ultrasonic, infrared and laser sensors, as well as LIDAR, depth and stereo vision cameras [29]. Figure 12 shows the system design.


Figure 12. System design

Today, autonomous vehicle technologies are advancing rapidly with the integration of Artificial Intelligence (AI) and deep learning algorithms. These developments require powerful processing capabilities and advanced AI-enabled hardware. NVIDIA Jetson Nano, a platform designed for robotic systems, was used as the main processor board. Jetson Nano manages the processes of collecting and processing data from various sensors in an autonomous vehicle, generating the corresponding control commands, and providing communication between the vehicle and the ground station via a Wi-Fi module. Electronic components connected to the main processor board:

- LIDAR (Laser Imaging Detection and Ranging) is a system that detects the position and distance of objects by sending laser pulses and calculating the return time of signals reflected from objects. In autonomous vehicles, LIDAR sensors continuously scan and map the vehicle's surroundings [30].
- Algorithms that combine camera, depth and image data are used to efficiently perform artificial intelligence tasks such as object recognition, path tracking and mapping.
- The weight sensor is responsible for calculating the weight of an object by measuring the strain on the vehicle. The data obtained from the sensor

76

is used to determine whether the lift is capable of lifting the load in question.
- Arduino Mega is a coprocessor board used to reduce the processing intensity on the main processor board.

Arduino is an open source physical programming platform that realizes basic input and output applications with peripherals using the processing/wiring language [31].

The Arduino Mega, preferred for its large number of input/output pins and ease of use, sends data from sensors and electronic components to the main processor card. The main processor provides motor control according to the data received from the board. Electronic components connected to the coprocessor board:

- Ultrasonic sensors are detection devices that measure the distance of objects with sound waves. By placing this sensor all around the vehicle, the autonomous vehicle can detect objects and avoid collisions by avoiding objects. This increases the vehicle's ability to maneuver effectively and ensures safe progress.
- IMU is an electronic unit that collects various
data | such | as | angular | velocity | (gyro),
acceleration, magnetic field and inclination (inclinometer) in a single sensor. These sensors are needed in areas such as factories where GNSS signals may be insufficient or interrupted [32].
- The motors and driver boards are controlled by Arduino Mega and used to control the motion of DC and servo motors.

### 2.4. Experimental setup

In the design of AMR, the weight and dimensions of the payload to be transported represent among the most critical factors that directly affect the payload capacity. In order to ensure the safe transportation of the load, it is imperative that the maximum weight does not exceed the capacity of the AMR. The design of the vehicle's transport platform is informed by an understanding of the dimensions of the load. In the process of sizing an AMR the physical characteristics of the area in which it will operate are taken into account. These include the width of roads, narrow passages, and the robot's ability to navigate these environments. Additionally, the design considers the presence of other equipment in the operational environment, such as safety sensors and emergency stop mechanisms. It also ensures that there is sufficient space for batteries and motors, preventing any potential hazards to personnel.

The payload carrying vehicle, which was designed as an original design unlike the current examples, is shown in Figure 14. When designing the vehicle, it was taken as a reference that it can go under a 50x95 cm platform and carry a load of 125 kg. Accordingly, the weight of the vehicle designed in 885×796×464 mm dimensions is approximately 60 kg. According to the dimensions of the vehicle, which is moved with the swerve driving system, the wheel dimensions were determined as 125x40 mm.

Figure 13. Closed and open state of the scissor system

The scissor system used for load carrying in the mobile robot is 400×360×120 mm in closed state and 400x360x323 in open state and is shown in Figure 13. In addition, the upper platform to which the scissors are connected can be opened to a height of 187 mm from the upper base of the vehicle. The chassis, to which the wheels are attached, and which carries the electronics and the lifting system, has dimensions of 460×500×218 mm. In designing the chassis, several considerations were taken into account, including the ability to safely carry the load and the lifting system, support for the body, dimensions that fit within the body, and sufficient space for electronic components.


Figure 14. Side view of the designed vehicle

The materials that are scheduled to be utilized in the production of the vehicle are stainless steel and an aluminum alloy. Stainless steel is renowned for its exceptional corrosion and rust resistance in industrial settings, which guarantees the AMR's durability and dependability over an extended period. Furthermore, stainless steel was selected for the scissors, pins, and cylinder due to its superior strength compared to aluminum alloys, which allows for the safe transportation of heavy loads. Aluminum alloy was selected for the body, chassis, wheel joints, and the upper and lower base of the lift due to its lightweight, durable, and easily machinable properties. The reduced weight of aluminum alloys results in decreased energy consumption, which in turn improves the vehicle's driving dynamics and increases maneuverability, thereby extending battery life [33]. The structural properties of the materials used in the mobile vehicle are shown in Table 2.

77

Table 2. Material information
Properties | Stainless Steel | Aluminum Alloy | Unit
Density | 7750 | 2770 | Kg m⁻³
Young's Modulus | 193000 | 71000 | MPa
Poisson Ratio | 0.31 | 0.33 | MPa
Shear Modulus | 73664 | 26692 | MPa
Yield Strength | 207 | 280 | MPa
Tensile Strength | 586 | 310 | MPa

The strategic selection of mesh sizes in ANSYS analysis is of great importance in terms of providing the appropriate sensitivity to different regions of the analysed structure. In this study, the smallest mesh size of 3 mm was preferred for critical connection points with high stress concentrations, joints of moving parts and areas with complex geometries. More detailed analyses were performed by using this small mesh size, especially in areas that require precise solutions such as connection points in the lever system and wheel connection areas.

Conversely, the largest mesh size employed in the analysis, 6 mm, was utilised in regions where the load density is more homogenously distributed and does not necessitate high precision. This approach was selected in order to optimise the solution time and reduce the computational load. The largest mesh size was employed for the wheel diameter, while the remaining components were modelled with appropriate mesh sizes between these two sizes. Consequently, different mesh sizes were chosen according to the requirements of each region, resulting in an optimal balance between solution time and accuracy.

The mesh, stress, and deformation analyses of the design were transferred to the static structural module of Ansys for analysis. Initially, a static analysis of the mesh was performed, which examined the real-world behavior of the analyzed parts under load. Based on the analysis, a determination was made regarding the suitability of the materials used in the design.

### 3. RESULTS

To obtain results approximating real-world conditions from finite element analyses conducted using Ansys, it is essential to carefully examine the values of element quality and skewness derived from the mesh analysis. Element quality can be calculated as the ratio of the volume to the sum of the squares of the edge lengths for 2D elements. In another way, for 3D elements, it is calculated as the square root of the cube of the sum of the squares of the side lengths. Element quality represents a composite quality metric ranging from zero to one. When the parameter value is ‘one’, it indicates an ideal cube or square. When the value is zero, it has a negative volume. [34].

For Mesh, skewness is one of the primary quality measures.Skewness determines the proximity of a face or cell to its ideal (equilateral or equiangular) shape. A skewness value approaching 0 indicates that the element closely approximates its ideal shape (e.g., equilateral shapes for triangular or quadrilateral elements). As the skewness value increases, the elements deviate further from the ideal shape, potentially distorting the analysis results. In Ansys, the skewness value is typically measured on a scale from 0 to 1, with a recommended maximum value of 0.95.Lower skewness values facilitate more accurate analysis results [35].

The results of the analysis show that element quality varies between 0.8 and 1 on average, while skewness is between 0.1 and 0.2. Therefore, it can be concluded that the deformation analysis, which evaluates how much a structure or material changes shape under applied forces and assesses its performance under real-world conditions, and the stress analysis, which determines the internal forces acting within a material and its ability to withstand applied loads, yield results that are close to reality.

The results of the analyses of the body, chassis, wheel mechanism, and lift system are listed in Table (3-6).

### 3.1. Body

For the outer shell of the vehicle, a body with dimensions of 885×670×355 mm was designed using aluminum alloy, which is a tough material. Figure 16 shows the element metric values of the different mesh types in the car body mesh analysis. It can be seen that element types such as tet10, hex20, wed15, tri3, and quad4 were used. This indicates that a hybrid mesh structure is preferred for representing the complex geometry of the model more accurately.For the outer shell of the vehicle, a body with dimensions of 885×670×355 mm was designed using aluminum alloy, which is a tough material.

The tet10 (tetrahedral) elements used in the analysis are typically preferred for irregular mesh structures and are useful for solving complex geometries. However, they do not provide the same level of accuracy as hexahedral elements do. In contrast, hex20 (hexahedral) elements, which occupy a large space in the model, offer a high solution accuracy and computational efficiency in regular mesh structures. Additionally, wed15 (wedge) elements are used in areas close to the surfaces of the model; these elements are beneficial in regions where triangular-based prismatic structures must align with complex surfaces. The surface elements in the model are represented by tri3 and quad4 elements. tri3 (triangular) elements are preferred for more complex surfaces and irregular areas, while quad4 (quadrilateral) elements are used to convert regular surfaces into a more homogeneous mesh structure [36-37].

In conclusion, the hybrid mesh structure was optimized according to the geometric characteristics by combining both regular and irregular elements. This strategy enhances the solution accuracy while balancing computational costs. In particular, the combined use of hex20 and tet10 elements allows for a denser mesh structure in critical areas, thereby increasing the reliability of the analysis results. The 3D model in Figure 15 illustrates the distribution of these elements over the model, showing the homogeneity of the mesh structure, both on the surface and within the internal structure.

78


Figure 15. Body mesh analysis

Figure 16 and the data presented in Table 3 were used to evaluate the quality of the mesh structure used in the vehicle body design and the geometric accuracy of its elements. The graph examines various quality metrics of the elements with two particularly significant metrics: element quality and skewness values.

The element quality is a critical factor in determining the analytical accuracy of mesh structures. The average element quality value is 0.78, which is considered acceptable, although the ideal value is closer to 1. A value of 0.78 indicates that most elements possess sufficient quality; however, some elements may exhibit reduced quality. The maximum element quality value is 1, indicating that some elements are of excellent quality, while the minimum quality value of 0.0295 suggests that certain elements have very low quality. Nonetheless, the presence of such low-quality elements in the non-load-bearing sections of the body is unlikely to significantly affect the overall accuracy of the results.

The skewness metric reflects the distortion in the shape of the elements. A low skewness value indicates a better element geometry. The maximum skewness value is 0.99, suggesting that some elements are nearly deformed. Such high skewness values can lead to erroneous deformation and stress analysis. The average skewness value of 0.3 is generally acceptable; however, caution may be necessary in regions where elements exhibit high skewness. The minimum skewness value of 1.3×10⁻¹⁰ is nearly zero, indicating that some elements have a very regular shape. Owing to the complex structure of the body, 1,463,049 elements and 2,798,461 nodes were utilized. This large number of elements signifies a detailed analysis and appropriate representation of the intricate geometry of the body.

These data suggest that, overall, the body mesh structure is sufficient, although improvements could be made in terms of element quality and skewness in certain areas. In particular, during the deformation and stress analyses, elements with high skewness may result in erroneous outcomes. However, considering that these areas do not bear loads, their effect on the overall analysis results is expected to be minimal.

Table 3. Body mesh analysis results
Number of Elements | Number of Nodes | Element Quality | Skewness
1463049 2798461 | | Max: 1 Avg: 0.78 Min: 0.0295 | Max: 0.99 Avg: 0.3 Min:1.3x10⁻¹⁰

The effects of the forces on the vehicle's body are evaluated through deformation analyses, as shown in Figure 16, while the stress analyses are presented in Figure 17. The deformation analysis illustrates the deformations that occur under an applied force of 325 N on the body. This analysis is critical for understanding the mechanical stability and durability of the body.

According to the analysis results, the deformation ranged from 0 to 0.55 mm. This is considered a very small deformation range. Given the dimensions of the vehicle body, this amount of deformation can be deemed insignificant. Considering that the body is not a primary load-bearing component and that a durable material such as aluminum alloy is used, it can be stated that this deformation does not pose a safety concern.

In conclusion, the body exhibits good resistance to the applied forces, and the resulting deformation is not significant enough to affect the structural integrity of the vehicle. This indicates that the body was designed safely, with minimal deformation occurring in sections that did not carry loads.

79


Figure 16. Vehicle body deformation analysis

The stress analysis illustrates the stresses occurring in various regions of the body under the same applied force of 325 N. The stress values range from 0 to 33.6 MPa. Considering the force applied on the body and the mechanical properties of the material, these stress levels are also quite low. Given the mechanical properties of aluminum alloy, these stress levels remain well below the yield limits of the material.

In other words, according to the stress analysis results, the body remained within a safe operating range under the applied forces. No excessive stress occurs in any part of the body, indicating that the design of the body possesses adequate durability against forces and pressures.


Figure 17. Vehicle body tension analysis

In other words, according to the stress analysis results, the body remained within a safe operating range under the applied forces. No excessive stress occurs in any part of the body, indicating that the design of the body possesses adequate durability against forces and pressures. Both analyses are critical simulations that examine the mechanical properties of the body. The deformation analysis in Figure 16 demonstrates that the body deforms minimally under applied forces. However, the stress analysis in Figure 17 shows that the stresses occurring in different regions of the body remain within a safe range. These results indicate that the design of the vehicle and the materials used are safe against forces and loads and are unlikely to cause issues in the long term.

### 3.2. Chassis

The chassis has dimensions of 460×500×218 mm and is generally rectangular. Therefore, the chassis, which carries the entire weight and load of the system, is one of the most critical components for autonomous vehicles. Accordingly, the chassis is designed using aluminum alloy, which is both lightweight and durable. The main reason for this is that aluminum increases the carrying capacity while simultaneously reducing the overall weight of the vehicle. In addition, aluminum alloys offer high strength and corrosion resistance, creating long-lasting and durable structures. This is especially critical for autonomous mobile vehicles that operate under harsh environmental conditions.

The mesh structure used in the analysis of the chassis was determined based on the complexity of the geometry and the accuracy of the analysis. Despite the rectangular structure of the chassis, a more flexible and adaptive mesh structure is required in some curved regions and corners. Therefore, the mesh structure shown in Figure 18 was obtained using tetrahedral (tet10) and hexahedral (hex20) elements together for the mesh element, and mesh analysis of this structure was performed. Tetrahedral elements were used in the geometrically complex and angular regions to capture fine details and model complex areas more precisely. On the other hand, hexahedral elements have a more regular structure, especially when used on flat surfaces and rectangular structures, and are preferred on wider and flatter surfaces. The choice of these mesh elements reduced the analysis time and at the same time increased the accuracy of the chassis analysis.


Figure 18. Chassis mesh analysis

80

The results of the mesh analysis for the chassis are presented in Table 4. According to this table, the chassis contains 43760 elements and 210717 nodes in total. The large number of elements allows the geometry to be modeled in detail and allows better determination of the stress and deformation values at different points of the structure. This is of great importance in the analysis of critical load-bearing structures such as chassis. The maximum element quality calculated in the analysis is 1, and the average quality is 0.89, indicating that the mesh structure is of very high quality. A high element quality improves the accuracy of the analysis results, allowing the stress distributions on the structure to be accurately calculated. On the other hand, skewness, which is another important parameter that evaluates the deformation of the mesh elements, was found to have a maximum value of 0.93 and an average skewness value of 0.1. A low skewness value indicates that the shape of the elements is close to their ideal geometry; thus, the analysis results are reliable.

Table 4. Chassis mesh analysis results
Number of Elements | Number of Nodes | Element Quality | Skewness
43760 | 210717 | Max: 1 Avg: 0.89 Min: 0.0527 | Max: 0.93 Avg: 0.1 Min: 1.3x10⁻¹⁰

The reference force of 1300 N applied to the chassis was calculated according to the lifting capacity of the vehicle and the maximum load it can carry. This force was applied to the chassis, and its durability and deformation capacity were tested. The deformation and stress analyses of the chassis are presented in Figures 19 and 20, respectively. As a result of the analysis, the total deformation values vary between 0 and 0.1878 mm. This deformation range shows that the chassis undergoes minimal deformation under load and, therefore, has sufficient structural strength. In addition, the stress values on the chassis were found between 2.71×10-6 MPa and 35.84 MPa. These values indicate that the material is within the safe operating range by maintaining its elastic limits.


Figure 19. Chassis deformation analysis

Based on the mesh and stress analyses, it is concluded that the chassis design is adequate in terms of both mesh quality and load-carrying capacity. A high-quality mesh structure and low skewness values indicate that the chassis provides reliable analysis results. Considering the stress and deformation results on the chassis, it is concluded that the design is suitable for the production phase.


Figure 20. Chassis tension analysis

### 3.3. Wheel Mechanism

A 125×40 mm drive wheel made of polyurethane material was used in an autonomous mobile vehicle with a Swerve driving system. The polyurethane material wheel, which was selected considering that the autonomous mobile vehicle will be operated in a factory environment, can be under load up to 250 kg; therefore, the wheels were selected as fixed points when performing deformation and stress analysis. The mesh analysis of the aluminum alloy apparatus, which is utilized for the attachment point to the vehicle and the connection of the motors, which are integral to the driving system, to the wheel (the most crucial component), is shown in Figure 21. To enhance the quality of mesh analysis, appropriate element types were selected for the components in question. Cartesian mesh analysis was employed for the rectangular and square parts, whereas the sweep method was used for the cylindrical regions. Additionally, body sizing and face sizing were applied to the remaining parts. Once the requisite mesh types were selected, enhancements were made to the analysis by determining the mesh size according to the overall characteristics of the part.

81


Figure 21. Wheel system mesh analysis

Upon examination of the mesh analysis results for the wheel system illustrated in Table 5, it becomes evident that the skewness and element quality values are calculated using 73,864 nodes and 25,743 elements following the implementation of the aforementioned improvements. Based on these calculations, the maximum skewness value is 0.92 and the average element quality value is 0.87. Because the values obtained were within the desired range, it is concluded that the mesh analysis is sufficient.

Table 5. Wheel system mesh analysis results
Number of Elements | Number of Nodes | Element Quality | Skewness
25743 | 73864 | Max: 1 Avg: 0.87 Min: 0.19 | Max: 0.92 Avg: 0.19 Min: 1.3x10⁻¹⁰

Mechanical analysis of the wheel mechanism was conducted under the assumption that the total weight of the vehicle with the maximum load (1800 N) would be borne by the wheels in the absence of friction.

The deformation and stress analyses of the wheel module as a function of the applied force are shown in Figures 22 and 23, respectively. As a result of these analyses, it can be seen that the total deformation value is between 0 and 0.04 mm, while the stress values are between 3.44×10-6 MPa and 75.37 MPa. Considering these results, it is observed that the wheel module is sufficiently durable to fulfill the desired task.


Figure 22. Wheel system deformation analysis


Figure 23. Wheel system stress analysis

### 3.4. Lift System

The vehicle's lifting system had dimensions of 400×360×323 mm. The upper and lower bases were constructed from aluminum alloys owing to their light weights. The scissors, cylinder, and pins were manufactured from stainless steel, owing to their durability. Analyses were conducted to assess whether these materials would also demonstrate the desired performance in practice. The results of the analysis are in accordance with the expected outcomes based on the calculations performed using the kinematic equations.

82


Figure 24. Lift system mesh analysis

Figure 25 illustrates the table of the mesh analysis for the element types, while Table 6 presents the results. As observed in Figure 24, tet10, hex20, and wed15 were utilized in the mesh analysis. As indicated in Table 6, there are 83944 elements and 381605 nodes. The average element quality value obtained from the table is 0.89, which indicates that the geometry is of a high quality and that the analysis can be conducted with confidence. The simplicity of the shape has resulted in the average skewness value coming out low at 0.098644. This indicates that the system is relatively balanced.

Table 6. Lift system mesh analysis results
Number of Elements | Number of Nodes | Element Quality | Skewness
83944 | 381605 | Max: 1 Avg: 0.89 Min: 0.23 | Max: 0.99 Avg: 0.0986 Min: 1.3x10⁻¹⁰

Figure 25 presents the results of the deformation analysis. The results indicate that the system is at a minimum deformation level, demonstrating high resistance to deformation. The maximum and minimum deformation values obtained are 0.65 mm and 0 mm. Figure 26 displays the stress analysis results against a 1250 N force applied to the system. The results indicate a maximum value of 58.76 MPa and a minimum value of 1.14×10⁻¹⁰ MPa. The choice of materials aluminum alloy and stainless steel confirms the system's outstanding resistance to stress and its capability to comfortably withstand loads up to 127.2 kg. Based on the analyses conducted, it can be concluded that the lift system designed is suitable for operational use.


Figure 25. Lift system deformation analysis

Figure 26. Lift system tension analysis

### 4. DISCUSSION AND CONCLUSION

This study focuses on the design, kinematic analysis, and mechanical durability of an autonomous mobile robot equipped with a scissor lift mechanism and a swerve drive system. The necessary electronic components for the vehicle's mobility and structural integrity have been identified, and kinematic formulas have been derived through theoretical calculations. The analyses conducted have confirmed that the vehicle can lift loads of the desired weight.

FEA was conducted utilizing Ansys to investigate the stress and deformation distributions of the vehicle under various loads, evaluating the vehicle's structural integrity

83

in simulated real-world conditions. A maximum deformation of 0.55 mm and a stress of 33.6 MPa were observed under a force of 325 N applied to the body. The chassis exhibited a maximum deformation of 0.1878 mm and a stress of 35.84 MPa under a load of 1300 N. The wheel mechanism demonstrated the capacity to support loads with a deformation of 0.04 mm and a stress of 75.37 MPa under a force of 1800 N. The lifting mechanism was analyzed with a force of 1250 N, resulting in a deformation of 0.65 mm and a stress of 58.76 MPa.

The analyses indicated that the vehicle, constructed of aluminum alloy and stainless steel, possesses the capacity to bear loads of up to 1250 N without significant deformation or stress. The quality of the mesh, skewness values, and element types (tet10, hex20 etc.) contributed to the accuracy and reliability of the analyses.

This study focuses on the avoidance system of the mobile robot, neglecting significant factors such as the control of the lever system and frictional forces. However, in practical applications, these omitted factors can substantially impact the vehicle's performance. Notably, temperature variations are critical to the long-term durability of the design. Thermal expansion at elevated temperatures or contraction at low temperatures can result in deformation and loss of precision in mechanical systems. Furthermore, particulate matter, prevalent in industrial environments, can increase frictional forces on wheel steering mechanisms, potentially leading to obstructions or wear. This may affect steering accuracy, particularly in independent wheel control systems. Additionally, while static load tests verify instantaneous structural durability, it is essential to consider that the vehicle will be subject to fatigue and wear effects during prolonged use. Repetitive loads can cause mechanical components to deteriorate over time, increasing the risk of failure. Moreover, the vibrations and sudden impacts that the mobile robot will experience in industrial applications can also negatively affect structural integrity. Considering these factors, it is evident that the elements disregarded in the design process can adversely impact the long-term performance and durability of the robot. Therefore, a more comprehensive analysis and testing against dynamic loads in conjunction with environmental factors could be conducted to obtain results more representative of real-world conditions.

Future research will encompass a more comprehensive analysis that incorporates the simulation of the lift system, as well as the effects of dynamic loads, friction, and dynamic behavior under varying operational conditions. Dynamic analysis—time-dependent assessments—will be conducted following the static analysis, as such analyses are more complex and time-consuming. However, they are essential for evaluating the system's performance under real-time external forces and changing speeds, ensuring reliable operation in real-world scenarios. Additionally, the development of path planning algorithms that enable the robot to navigate safely by sensing its environment is proposed. The application of deep learning methods and camera-based image processing techniques for object recognition will also be considered. Furthermore, techniques for effective mapping will be explored, enabling the robot to create a map of its environment and utilize it efficiently. Research will be conducted on SLAM (Simultaneous Localization and Mapping) algorithms, which allow robots to determine their positions while mapping unknown environments. The Gazebo simulation environment has been selected for these studies. The preference for Gazebo over CoppeliaSim is attributed to Gazebo's broader resources and the availability of numerous ready-made packages that can integrate seamlessly with ROS (Robot Operating System). This will facilitate more efficient and straightforward execution of tasks such as mapping, image processing, and simulation integration.

REFERENCES

[1] Haruna AI, Sankar R, Samaila A. Design and development of an instructional mobile robot for
effective | learning | of material | handling | in
mechanical workshops in universities. Mater Today Proc. 2023.
[2] Corke | P. | Robotics, | Vision | and | Control:
Fundamental Algorithms in MATLAB®. 1st ed. Berlin: Springer-Verlag; 2011.
[3] Tagliavini L, Colucci G, Botta A, Cavallone P, Baglieri L, Quaglia G, et al. Wheeled Mobile Robots: State of the Art Overview and Kinematic
Comparison | Among | Three | Omnidirectional
Locomotion Strategies. J Intell Robot Syst. 2022;106(3).
[4] Raikwar S, Fehrmann J, Herlitzius T. Navigation and control development for a four-wheel-steered mobile orchard robot using model-based design. Comput Electron Agric. 2022; 202:105432.
[5] Yamaç Hİ, Yılmaz T. Mobil Robotlar için Yük Altındaki Davranış Analizinin İncelenmesi. Fırat
Üniversitesi | Mühendislik | Bilimleri | Dergisi.
2022;34(1):433-8.
[6] Roland Siegwart and Illah R. Nourbakhsh, Introduction to Autonomous Mobile Robots, 1st ed. Cambridge, Massachusetts: MIT Press; 2004.
[7] Demir C, Bozdemir M. Swedish tekerlekli mobil robot tasarımı ve 3b yazıcıyla imalatı, 4th International Congress On 3d Printing (Additive Manufacturıng) Technologies and Digital Industry, Antalya: 2019. p. 144-153.
[8] Huang H, Gao J. Backstepping and Novel Sliding Mode Trajectory Tracking Controller for Wheeled Mobile Robots. Mathematics. 2024;12(10):1458.
[9] Nikishkov GP. Introduction To The Finite Element Method. Japan: 2004 Lecture Notes. University of Aizu, Aizu-Wakamatsu 965-8580; 2004
[10] Baskoro CHAHB, Saputra HM, Mirdanies M, Susanti V, Radzi MF, Aziz RIA. An Autonomous Mobile Robot Platform for Medical Purpose. 2020 International Conference on Sustainable Energy Engineering and Application (ICSEEA). Tangerang: IEEE; 2020. p. 41-44.
[11] Yan SYW, Chamniprasart K, Phueakthong P, Pinrath N. Autonomous Mobile Robot for Material Handling in an Industrial Plant. The Annual

84

Conference on Engineering and Information Technology. Osaka: ACEAIT; 2023.
[12] Dhelika R, Hadi AF, Yusuf PA. Development of a Motorized Hospital Bed with Swerve Drive Modules for Holonomic Mobility. Applied Sciences. 2021;11(23):11356.
[13] Zhao Z, Xie P, Meng MQ-H. ODD: Omni Differential Drive for Simultaneous Reconfiguration and Omnidirectional Mobility of Wheeled Robots. arXiv preprint arXiv:2407.10127 (2024).
[14] Demir N, Sucuoglu HS, Bogrekci I, Demircioglu P. Structural & Dynamic Analyses and Simulation of Mobile Transportation Robot. Int. J. of 3D Printing Tech. Dig. Ind. 2021; 5(3): 587- 595.
[15] Prabhakaran S, Aravinth KT, Adhik N, Vikram R. Design and Analysis of Autonomous Mobile Robot. Nat. Volatiles & Essent. Oils. 2021; 8(5): 3020-3030.
[16] Koca YB, Gökçe B, Aslan Y. ROS/Gazebo Ortamında Tank Sürüş Özellikli Mobil Bir Robotun
Similasyonu. | Journal | of | Materials | and
Mechatronics: A (JournalMM). 202; 1(1), 29-41.
[17] Ağralı E, Çavaş M. V-REP Robotik Simülatör ile
Robot | Kol | Simülasyonu. | Fırat | Üniversitesi
Mühendislik Bilimleri Dergisi. 2020;32(2):435-44.
[18] Akin JE. Finite Element Analysis Concepts via SolidWorks. Rice University. Houston, Texas; 2009.
[19] Aksoy S. Makas Platformlu Mobil Robot Tasarımı ve Analizi [Bitirme Tezi]. Konya: Konya Teknik Üniversitesi Mühendislik ve Doğa Bilimleri Fakültesi; 2023.
[20] Madier D. An Introduction to the Fundamentals of Mesh Generation in Finite Element Analysis. FEA Academy; 2023
[21] Ansys. The Fundamentals of FEA Meshing for Structural Analysis. 2021 April 28 [cited 2024
September | 28]. | Available | from:
https://www.ansys.com/blog/fundamentals-of-fea-meshing-for-structural-analysis (https://www.ansys.com/blog/fundamentals-of-fea-meshing-for-structural-analysis)
[22] Cadsay. Ansys nedir?. [cited 2024 April 28]. Available from: https://cadsay.com/ansys-nedir
[23] Coppelia Robotics. CoppeliaSim. [cited 2024 April
27]. | Available | from:
https://www.mathworks.com/products/connections/product_detail/coppeliasim.html (https://www.mathworks.com/products/connections/product_detail/coppeliasim.html)
[24] Büyükarslan P. Spyder Nedir? Nasıl Kurulur?. [cited
2024 | April | 30]. | Available | from:
https://www.sistemlinux.org/2018/05/spyder-nedir-nasil-kurulur.html (https://www.sistemlinux.org/2018/05/spyder-nedir-nasil-kurulur.html)
[25] Adar NG. Mobil İnsansı Robot Tasarımı İmalatı ve
Kontrolü | [Doktora | Tezi]. | Sakarya: | Sakarya
Üniversitesi Fen Bilimleri Enstitüsü; 2016.
[26] van der Velde P. Swerve drive introduction. 2022 December 4 [cited 2023 Jun 13]. Available from: https://www.petrikvandervelde.nl/posts/Swerve-drive-introduction (https://www.petrikvandervelde.nl/posts/Swerve-drive-introduction)
[27] Chiefdelphi, Whitepaper: Swerve Drive Skew and Second Order Kinematics. 2022 November [cited
2023 | Jun | 10]. | Available | from:
https://www.chiefdelphi.com/t/whitepaper-swerve-drive-skew-and-second-order-kinematics/416964 (https://www.chiefdelphi.com/t/whitepaper-swerve-drive-skew-and-second-order-kinematics/416964)
[28] Gong Z, Nie Z, Liu Q, Liu XJ. Design and control of a multi-mobile-robot cooperative transport system based on a novel six degree-of-freedom connector. ISA Trans. 2023;139:606-20.
[29] Sukop M, Grytsiv M, Jánoš R, Semjon J. Simple Ultrasonic-Based Localization System for Mobile Robots. Applied Science. 2024;14(9):3625.
[30] Akyol S, Uçar A. Rp-Lidar ve Mobil Robot Kullanılarak Eş Zamanlı Konum Belirleme ve Haritalama. Fırat Üniversitesi Mühendislik Bilimleri Dergisi. 2019;31(1):137-43.
[31] Güngör O. Kaçak Elektrik Kullanımının GSM
Aracılığıyla | Takibi. | EMO | Bilimsel | Dergi.
2015;4(8):29-34.
[32] Nalbantoğlu V, Seymen B. Ataletsel Seyrüsefer Sistemleri. Mühendis ve Makina. 2007;48(566):7-13.
[33] JR Callister WD, Rethwisch DG. Materials Science and Engineering: An Introduction. 10th ed. Hoboken, NJ: Wiley; 2018.
[34] FEATips. ANSYS Mesh Metrics Explained. 2022 November 21 [cited 2024 June 15]. Available from: https://featips.com/2022/11/21/ansys-mesh-metrics-explained/ (https://featips.com/2022/11/21/ansys-mesh-metrics-explained/)
[35] Simscale. Mesh Quality. 2024 July 30 [cited 2024
September | 20]. | Available | from:
https://www.simscale.com/docs/simulation-setup/meshing/mesh-quality/ (https://www.simscale.com/docs/simulation-setup/meshing/mesh-quality/)
[36] Bommes (https://onlinelibrary.wiley.com/authored-by/Bommes/David) D, Lévy (https://onlinelibrary.wiley.com/authored-by/L%C3%A9vy/Bruno) B, Pietroni (https://onlinelibrary.wiley.com/authored-by/Pietroni/Nico) N, Puppo (https://onlinelibrary.wiley.com/authored-by/Puppo/Enrico) E, Silva (https://onlinelibrary.wiley.com/authored-by/Silva/Claudio) C, Tarini M, et al. Quad-Mesh Generation and Processing: A Survey. Computer Graphics Forum. 2013;32(6): 51-76.
[37] Motooka Y, Noguchi S, Igarashi H. Evaluation of Hexahedral Mesh Quality for Finite Element Method in Electromagnetics. Materials Science Forum. 2010;670:318–324.

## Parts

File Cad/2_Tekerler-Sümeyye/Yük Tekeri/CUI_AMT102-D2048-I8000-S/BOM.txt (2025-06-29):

3DX_CUI_Supplier: CUI, Inc
3DX_CUI_Description: AMT10 Radial, Adjustable Resolution, 2048 PPR, Single Index Pulse, 8 mm Bore, Standard, Incremental, Capacitive Modular Encoder
3DX_CUI_Model Number: AMT102-D2048-I8000-S

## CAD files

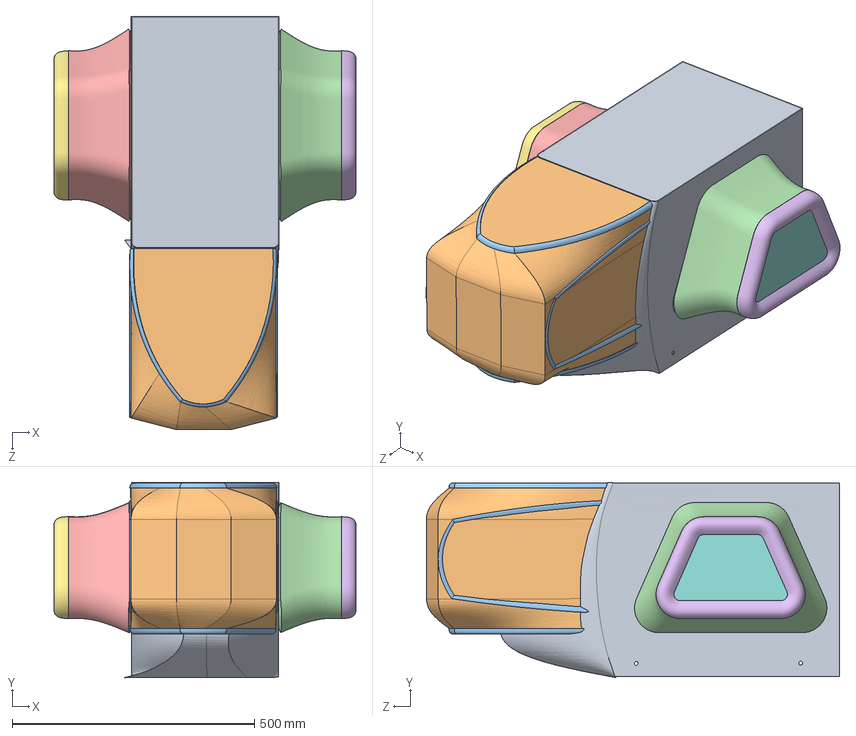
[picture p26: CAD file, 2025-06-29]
Cad/0_Dış Görünüş-Melike/Çizim_2/pisicik_02.SLDASM
623.1 x 402.8 x 852.8 mm
Ana_Govde_02
On_Govde_Cam_01
On_Govde_01
Sag_yan_govde_01
Sol_yan_govde_01
Sag_yan_kapak_01
Sol_yan_kapak_01
Sag_yan_kapak_cam_01
Sol_yan_kapak_cam_01

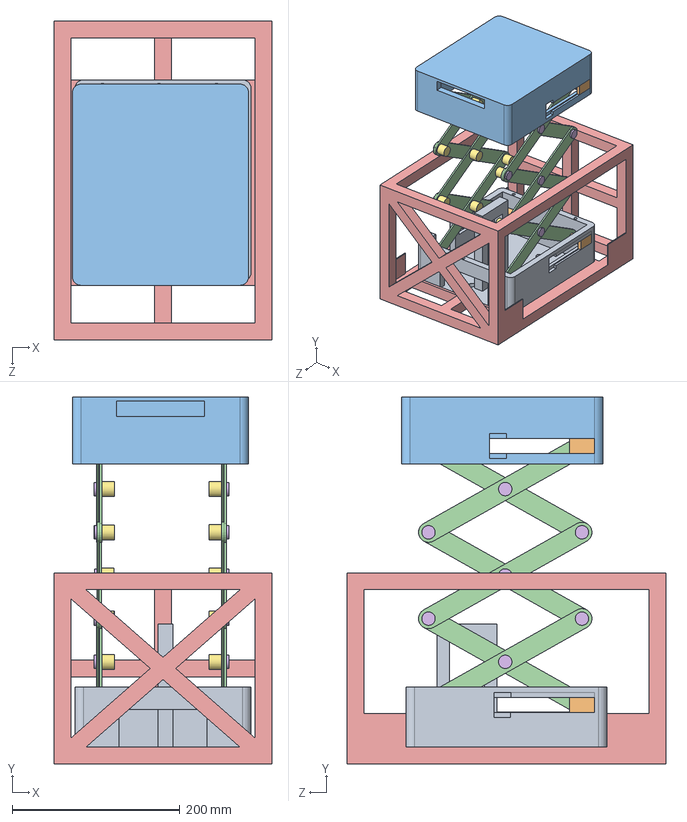
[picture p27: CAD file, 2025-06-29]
Cad/3-Şasi-Görkem/1/00_Chassis-Lifting System.SLDASM
260.0 x 437.8 x 380.0 mm
02_Battom of Lifting
04_Platform Slider x 4
03_Top of Lifting
07_Scissor Lift Arm x 12
01_Chassis
05_Rivet Bolt x 14
09_Rivet Cap 2 x 18

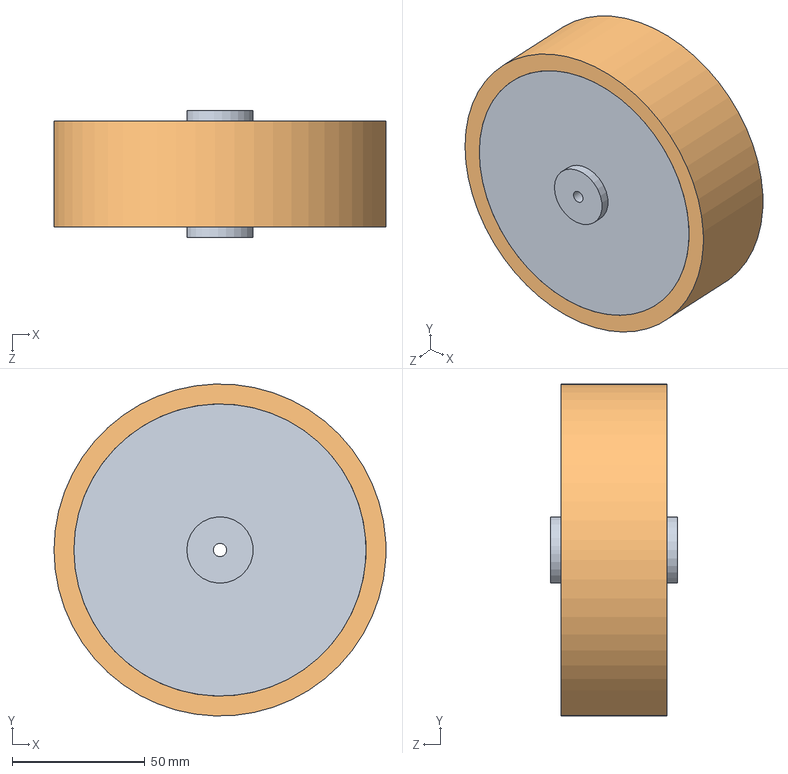
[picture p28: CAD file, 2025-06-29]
Cad/2_Tekerler-Sümeyye/teker/teker/D0_Ana Teker.SLDASM
125.0 x 124.9 x 48.0 mm
D1_Teker içi
D2_Teker lastiği

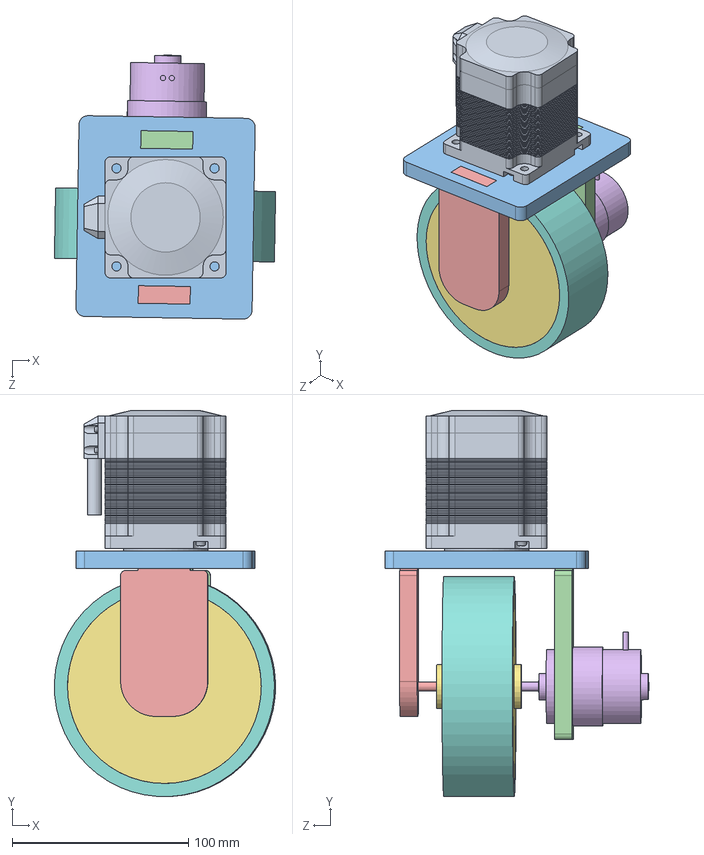
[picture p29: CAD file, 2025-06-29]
Cad/2_Tekerler-Sümeyye/Yük Tekeri 2/D0_Teker.SLDASM
125.6 x 219.1 x 150.0 mm
D4_Servo motor
D8_İç mil servo
D3_Servo altı
D6_Yan panel sağ
D7_Yan panel sol
D5_Motor
D1_Teker içi
D2_Teker lastiği

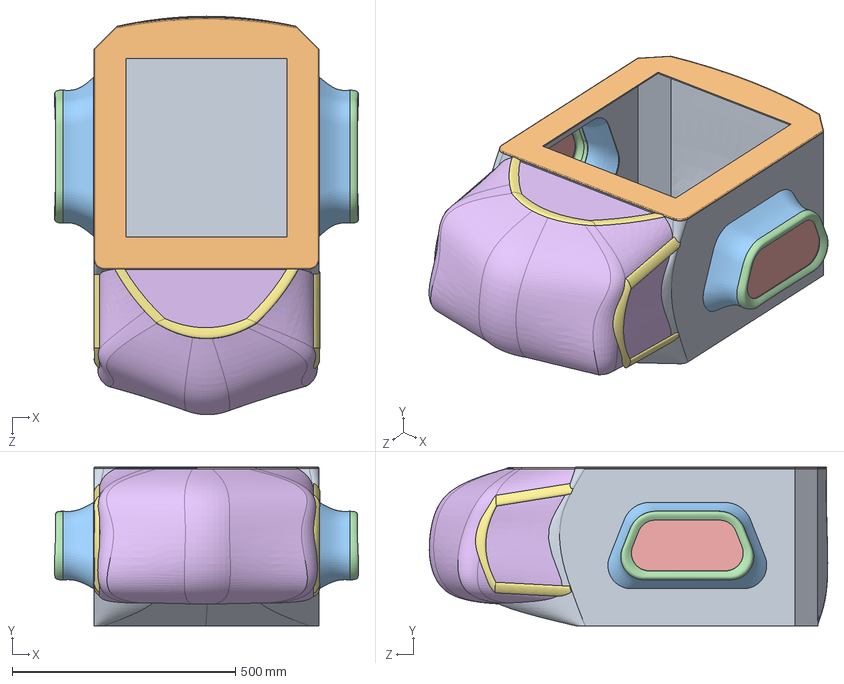
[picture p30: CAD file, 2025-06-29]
Cad/swerve load robot/A0_DışTasarım.SLDASM
681.3 x 355.7 x 893.2 mm
A1_Ana Gövde 5
A2_Ana Gövde Üst Kapak 5_2
A4_Yan Gövde 5 x 2
A5_Yan Gövde Kapak 5 x 2
A6_Yan Gövde Cam 5 x 2
A3_Ön Cam 5
A7_Ön Cam Kenar 5

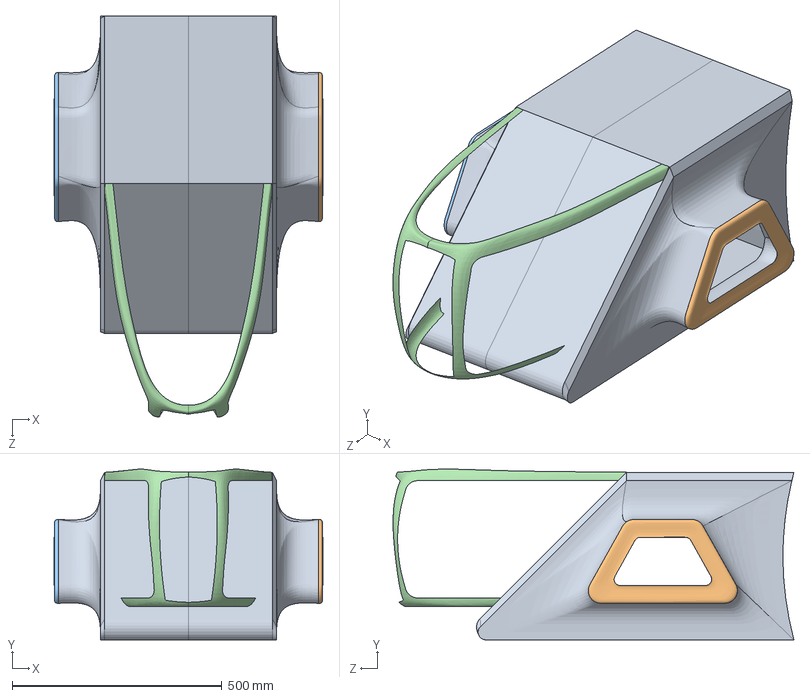
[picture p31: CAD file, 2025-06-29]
Cad/0_Dış Görünüş-Melike/Çizim_1/BTU_X_1.SLDASM
642.0 x 407.5 x 956.8 mm
Ana Gövde 1
Sag Yan Kapak 1_2
Sol Yan Kapak 1
Ön Gövde 1_2

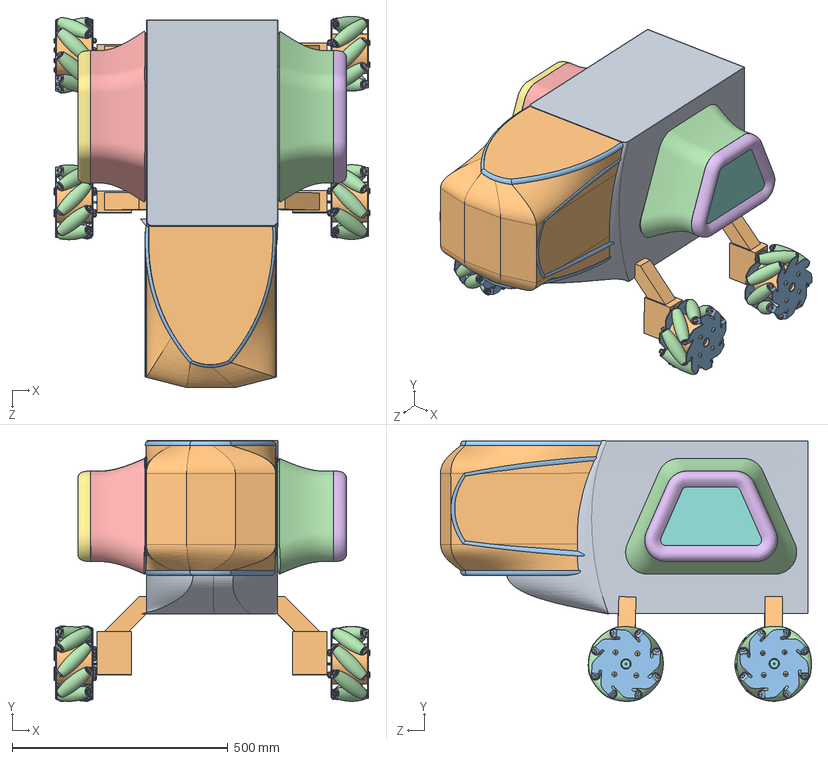
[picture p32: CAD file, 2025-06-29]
Cad/0_Dış Görünüş-Melike/Çizim_2/final hali.SLDASM
732.8 x 605.4 x 860.8 mm
Ana_Govde_02
On_Govde_Cam_01
On_Govde_01
Sag_yan_govde_01
Sol_yan_govde_01
Sag_yan_kapak_01
Sol_yan_kapak_01
Sag_yan_kapak_cam_01
Sol_yan_kapak_cam_01
shaft x 4
panelAynalanmış x 4
rollerr x 32
bolt x 32
torque nut 05_iso x 48
shaftbolt x 16
teker içi x 4
dc motor x 4
teker bağlantı kısmı x 4
panel x 4

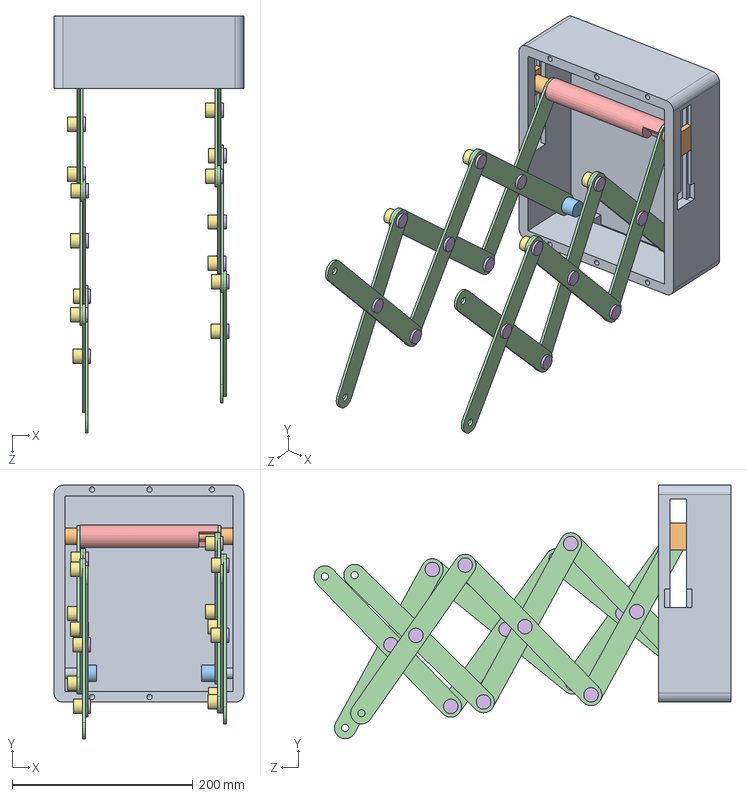
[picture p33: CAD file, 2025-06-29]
Cad/1_Kaldıraç-Zeynep/0/üst taban montaj.SLDASM
210.0 x 280.4 x 461.2 mm
üst taban
makas taban arası vida x 2
vida kasası x 2
makas x 12
silindir yeni
makas montaj parçası 1 x 14
makas montaj parçası 2 x 14

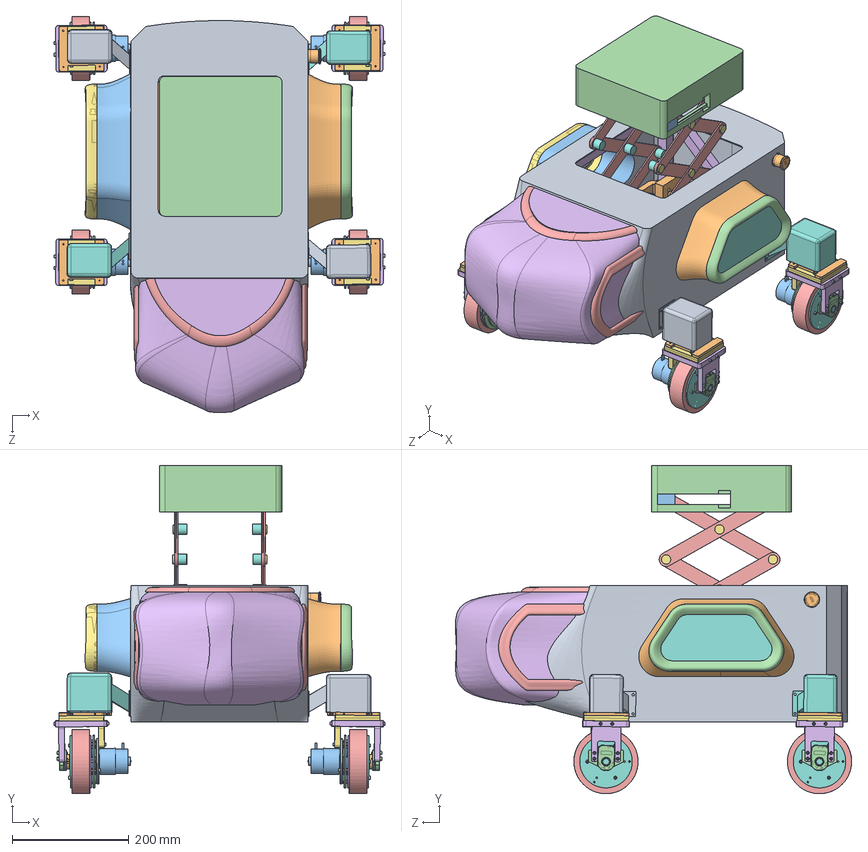
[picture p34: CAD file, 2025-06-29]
Cad/0_Dış Görünüş-Melike/Çizim_4/BTU_X 4.SLDASM
567.2 x 562.7 x 679.3 mm
Ana Gövde 4
Sağ Yan Gövde 4
Sol Yan Gövde 4
Sağ Yan Gövde Kapak 4
Ön Gövde 4
Ön Gövde Cam 4_2
Sol Yan Gövde Kapak 4
Sağ Yan Gövde Kapak Cam 4
Sol Yan Gövde Kapak Cam 4
Force stop button
CUI_amt-102-base-rev-k x 4
CUI_amt-102-top-cover-rev-h x 4
CUI_amt-hub-top-rev-d1 x 4
CUI_amt-hub-bottom-rev-b x 4
CUI_receiver-board x 4
CUI_rotor-board-rev f x 4
CUI_transmitter-board amt10(amt-102) x 4
motor_sp6 x 4
IG42C(1_14,17,24) x 4
motor_sp(1) x 4
6-12bearing x 24
obj1 x 12
PC obj4 x 4
rool(______) x 12
motor_sp2 x 4
RZ735-VA-1 x 4
motor_sp4-1 x 4
motar_sp7 x 4
motor_sp4_a x 4
obj2 x 12
motor_sp3(______) x 4
motor_sp10_b x 12
Al_5mm_obj2 x 4
motor_sp5 x 4
__8mm __12mm x 4
PC obj3-1 x 4
motor_sp6_a x 4
AMT sub shaft-1 x 4
M3________(10)-1 x 32
M3________(5) x 24
M3________(35) x 12
M3________(15) x 32
M3________(20) x 16
___ 75_ L-33 x 8
servo 60 x 4
servo 60 top x 4
PC obj10sv(3mm) x 4
PC obj11sv x 8
PC obj7 x 4
M2.5____ x 28
PC obj5(3mm) x 4
M3____ x 16
Teker bağlama 1 x 2
Teker bağlama 2 x 2
02_Battom of Lifting
04_Platform Slider x 4
03_Top of Lifting
07_Scissor Lift Arm x 12
01_Chassis
05_Rivet Bolt x 14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

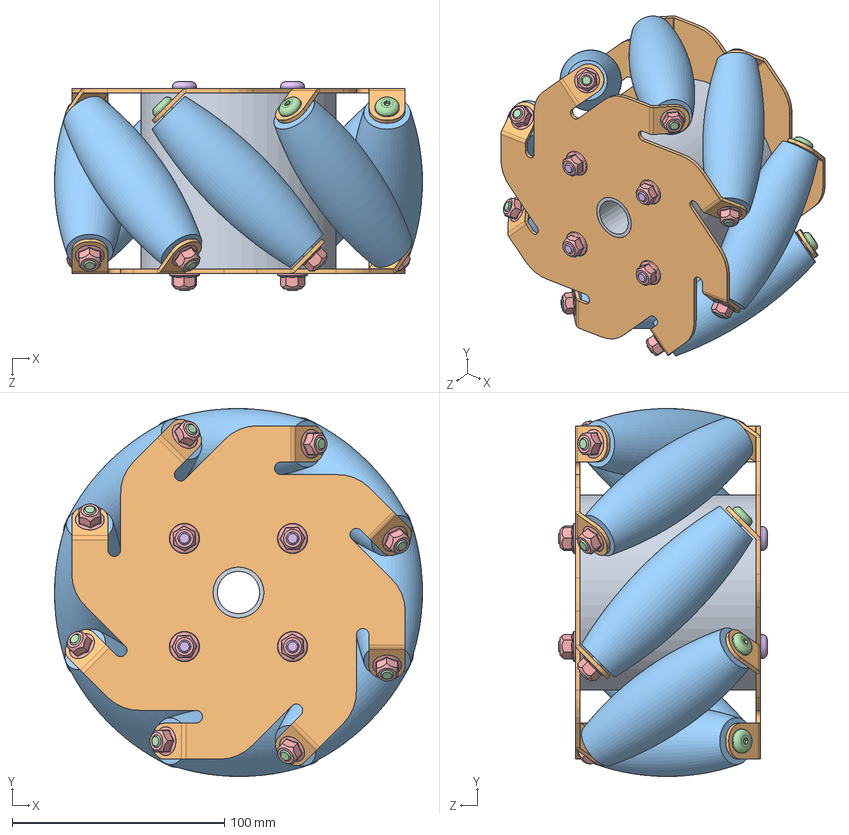
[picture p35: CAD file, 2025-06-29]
Cad/2_Tekerler-Sümeyye/mecanum tekerler/sağ tekerlek.SLDASM
173.3 x 173.3 x 98.3 mm
shaft
panelAynalanmış x 2
rollerr x 8
bolt x 8
torque nut 05_iso x 12
shaftbolt x 4

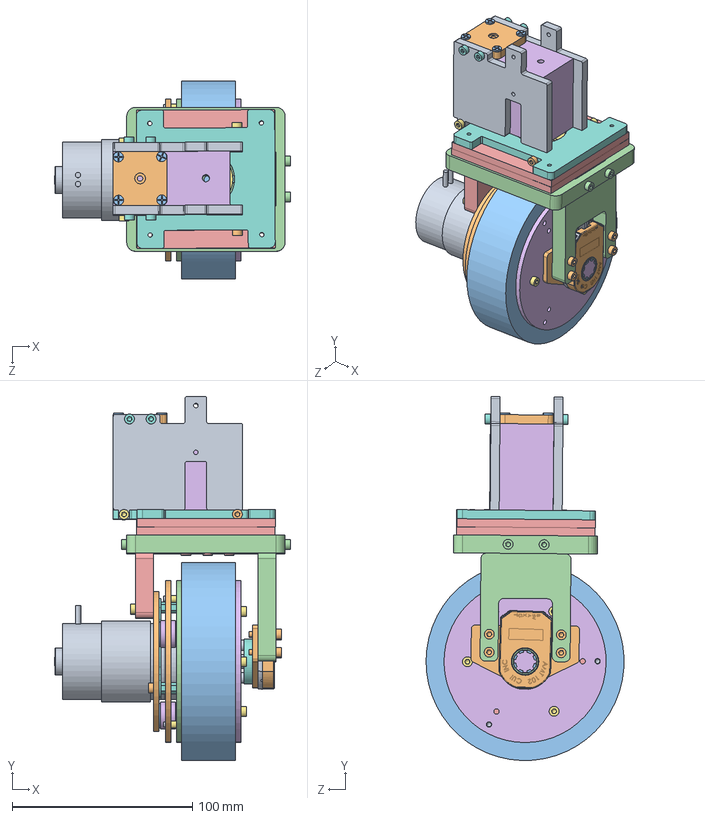
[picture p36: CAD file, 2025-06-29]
Cad/2_Tekerler-Sümeyye/Yük Tekeri/x/swerve drive.SLDASM
131.1 x 202.1 x 109.9 mm
CUI_amt-102-base-rev-k
CUI_amt-102-top-cover-rev-h
CUI_amt-hub-top-rev-d1
CUI_amt-hub-bottom-rev-b
CUI_receiver-board
CUI_rotor-board-rev f
CUI_transmitter-board amt10(amt-102)
motor_sp6
IG42C(1_14,17,24)
motor_sp(1)
6-12bearing x 6
obj1 x 3
PC obj4
rool(______) x 3
motor_sp2
RZ735-VA-1
motor_sp4-1
motar_sp7
motor_sp4_a
obj2 x 3
motor_sp3(______)
motor_sp10_b x 3
Al_5mm_obj2
motor_sp5
__8mm __12mm
PC obj3-1
motor_sp6_a
AMT sub shaft-1
M3________(10)-1 x 8
M3________(5) x 6
M3________(35) x 3
M3________(15) x 8
M3________(20) x 4
___ 75_ L-33 x 2
servo 60
servo 60 top
PC obj10sv(3mm)
PC obj11sv x 2
PC obj7
M2.5____ x 7
PC obj5(3mm)
M3____ x 4

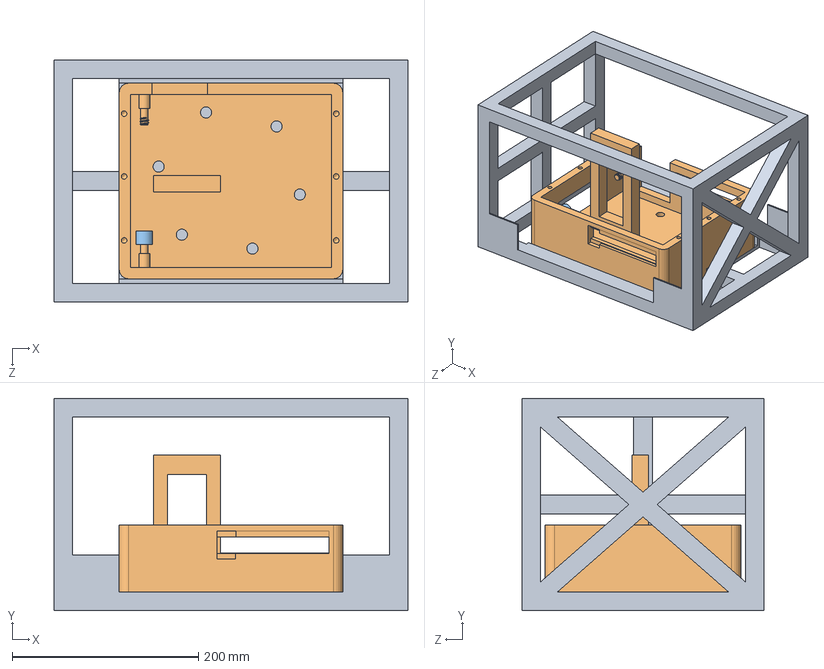
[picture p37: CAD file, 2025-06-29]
Cad/1_Kaldıraç-Zeynep/0/şase+alt[1].SLDASM
380.0 x 228.0 x 260.0 mm
sase
alt taban
vida kasası

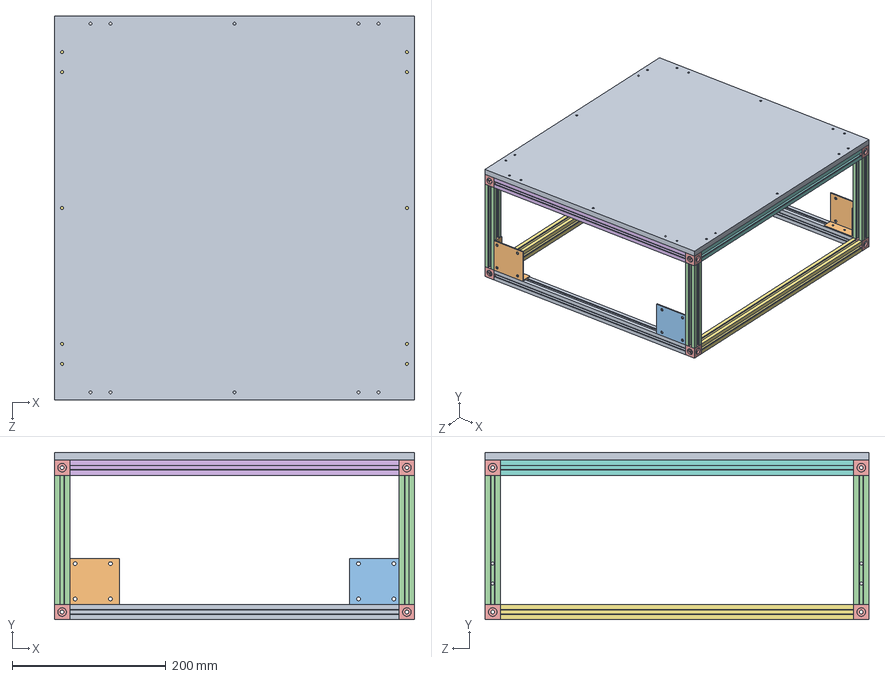
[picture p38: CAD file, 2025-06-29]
Cad/swerve load robot/C0_Şase Montaj.SLDASM
469.0 x 218.0 x 500.0 mm
C2_Profil Boy Alt x 2
C5_Sol Köse Parçasi x 2
C5_Sag Köse Parçasi x 2
C3_Profil Yükseklik x 4
C6_Küp Köse Baglantisi x 8
C2_Profil Boy Üst x 2
C4_Profil En Alt x 2
C4_Profil En Üst x 2
C1_ Üst Taban

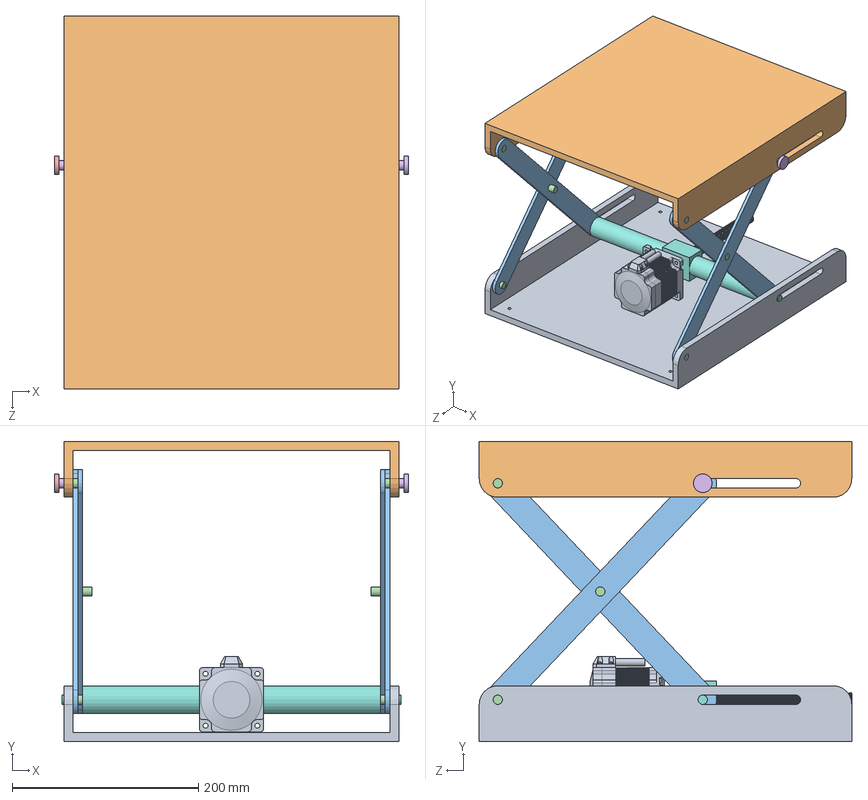
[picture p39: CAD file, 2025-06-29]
Cad/swerve load robot/B0_Lifting System.SLDASM
380.0 x 322.4 x 400.0 mm
B1_Alt Platform
B1_Platform
B2_Scissor x 4
B6_Pim x 6
B5_Platform Slider x 2
B5_Platform Slider 2 x 2
B3_Cylinder

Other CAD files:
Cad/2_Tekerler-Sümeyye/Yük Tekeri/CUI_cui_amt102-d0048-i8000-s.SLDASM
Cad/2_Tekerler-Sümeyye/mecanum tekerler/sol teker.SLDASM
Cad/0_Dış Görünüş-Melike/Çizim_3/BTU_X.SLDASM
Cad/0_Dış Görünüş-Melike/Çizim_1/Ana Gövde 1.SLDPRT
Cad/0_Dış Görünüş-Melike/Çizim_1/Part1.SLDPRT
Cad/0_Dış Görünüş-Melike/Çizim_1/Sag Yan Kapak 1_2.SLDPRT
Cad/0_Dış Görünüş-Melike/Çizim_1/Sol Yan Kapak 1.SLDPRT
Cad/0_Dış Görünüş-Melike/Çizim_1/Yan Kapak 1_1.SLDPRT
Cad/0_Dış Görünüş-Melike/Çizim_1/Ön Gövde 1_1.SLDPRT
Cad/0_Dış Görünüş-Melike/Çizim_1/Ön Gövde 1_2.SLDPRT
Cad/0_Dış Görünüş-Melike/Çizim_2/Ana_Govde_02.SLDPRT
Cad/0_Dış Görünüş-Melike/Çizim_2/On_Govde_01.SLDPRT
Cad/0_Dış Görünüş-Melike/Çizim_2/On_Govde_Cam_01.SLDPRT
Cad/0_Dış Görünüş-Melike/Çizim_2/Sag_yan_govde_01.SLDPRT
Cad/0_Dış Görünüş-Melike/Çizim_2/Sag_yan_kapak_01.SLDPRT
Cad/0_Dış Görünüş-Melike/Çizim_2/Sag_yan_kapak_cam_01.SLDPRT
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
